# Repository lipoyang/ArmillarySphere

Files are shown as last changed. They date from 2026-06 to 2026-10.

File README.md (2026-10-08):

# 動く渾天儀
ステッピングモータで動く渾天儀です。

## 解説
* [動く渾天儀 | ProtoPedia](https://protopedia.net/prototype/8534) (日本語記事)
* [Motorized Armillary Sphere - Hackster.io](https://www.hackster.io/lipoyang/motorized-armillary-sphere-933569) (英文記事)

## ファイル
* [./app/](./app/) : Webアプリのソース (Chrome系ブラウザ対応。iOSは非対応)
* [./firm/](./firm/) : マイコンのソース (PlatformIOのプロジェクト)
* [./hard/](./hard/) : 回路の資料
* [./mechanical/](./mechanical/) : 機械設計 (Autodesk Fusionで設計)

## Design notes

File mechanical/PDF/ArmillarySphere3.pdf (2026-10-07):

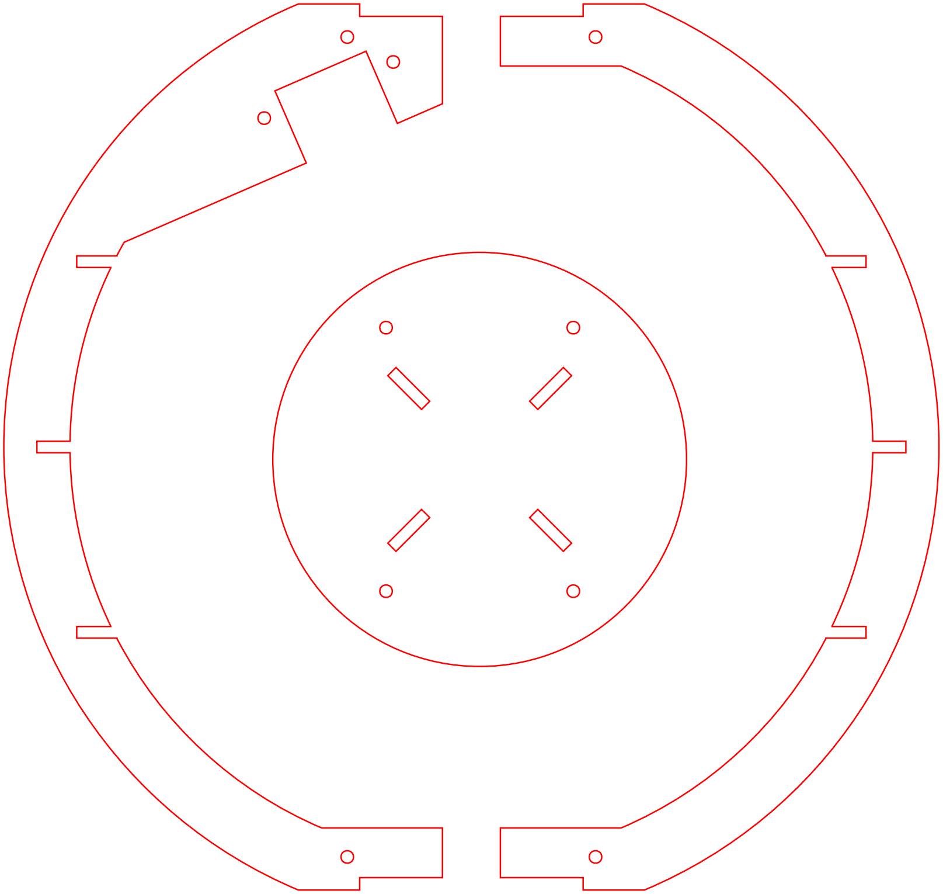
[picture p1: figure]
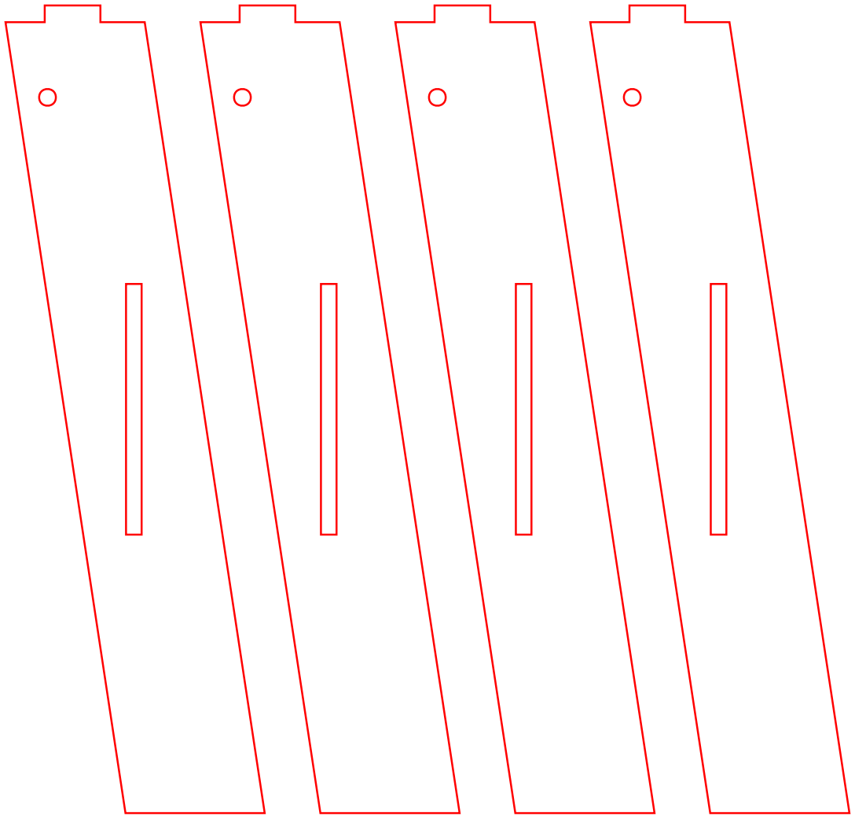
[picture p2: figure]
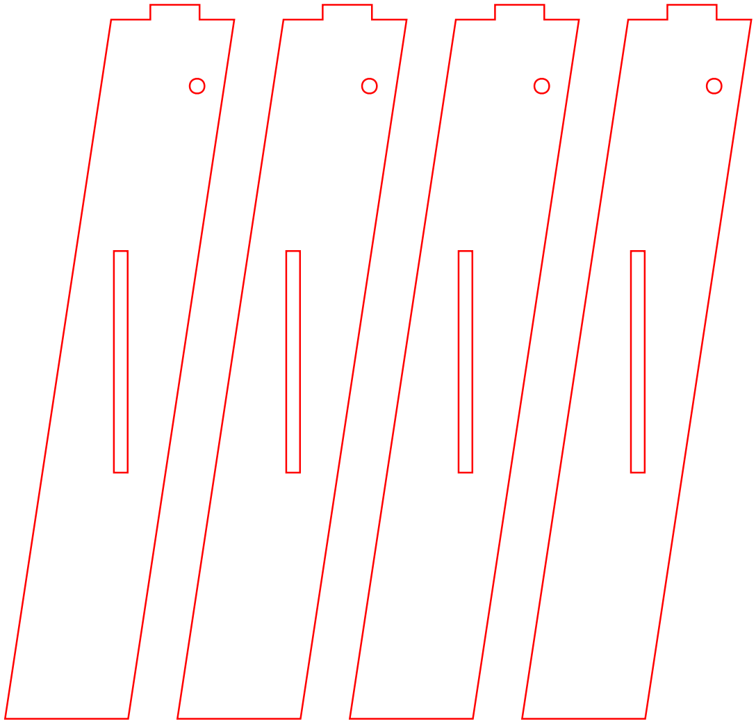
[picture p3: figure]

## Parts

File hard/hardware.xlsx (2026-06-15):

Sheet: 部品表
型番 | 説明 | 個数
~~XIAO nRF52840~~ | ~~マイコン~~ | ~~1~~
M5Stack Basic | マイコン | 1
Pololu DRV8825 モータドライバモジュール | ステッピングモータドライバモジュール | 2
24BYJ48 (12V) | 2相ユニポーラ ステッピングモータ ステップ角 = 5.625°、ギア比 = 1/64 | 2
SK8552 | ホールセンサ | 2
橙色LED (汎用品) | 太陽の表示用LED | 1
SNM022A-12 | スリップリング 12極 | 1
ACアダプタ 12V 1.5A (汎用品) | 電源用、DCプラグ φ2.1mm | 1
ユニバーサル基板 Cタイプ (汎用品) | 72×47mm ノンスルーホール | 1
JST EH 4ピン | モータとホールセンサのケーブル用コネクタ | 3
JST EH 2ピン | LEDのケーブル用コネクタ | 1
DCジャック φ2.1mm (汎用品) | 電源用 | 1
BP5293-50 | DCDCコンバータ 5V 1A | 1
電解コンデンサ 33uF 10V (汎用品) | 電源安定用 | 1
ショットキーバリアダイオード SS2040FL | 5V電源の衝突防止用ダイオード | 1
NPNデジトラ DTC014EEB | LEDのオンオフ用デジトラ | 1
100Ω抵抗 (汎用品) | LEDの電流制限抵抗 | 1

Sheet: マイコンのピンピン配置
ピン | 接続先 | ピン | 接続先 | 参考 | https://wiki.seeedstudio.com/ja/XIAO_BLE/
D0 | モータ1 DIR | VBUS | 5V
D1 | モータ1 STEP | GND | GND
D2 | モータ2 DIR | 3.3V | 3.3V
D3 | モータ2 STEP | D10 | ホールセンサ2
D4 | 未接続 | D9 | ホールセンサ1
D5 | 未接続 | D8 | LED
D6 | 未接続 | D7 | 未接続

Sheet: モータドライバのピン配置
ピン | 機能 | 接続先 | ピン | 機能 | 接続先 | 参考 | https://www.pololu.com/product/2133
8 | nENABLE | GND | 1 | VMOT | +12V
7 | MODE0 | 未接続 | 2 | GND | GND
6 | MODE1 | 未接続 | 3 | B2 | モータ
5 | MODE2 | 未接続 | 4 | B1 | モータ
4 | nRESET | +3.3V | 5 | A1 | モータ
3 | nSLEEP | +3.3V | 6 | A2 | モータ
2 | STEP | マイコン | 7 | FAULT | 未接続
1 | DIR | マイコン | 8 | GND | GND

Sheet: コネクタのピン配置
■ モータ
ピン | 信号名
1 | B2
2 | B1
3 | A1
4 | A2
■ LED
ピン | 信号名
1 | アノード
2 | カソード
■ ホールセンサ
ピン | 信号名
1 | +3.3V
2 | ホールセンサ1
3 | ホールセンサ2
4 | GND

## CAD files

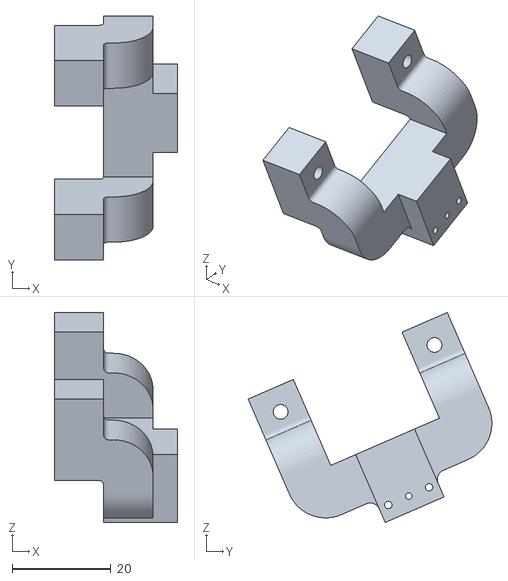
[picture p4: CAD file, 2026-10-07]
mechanical/STL/motor2_adapter.stl
25.0 x 49.4 x 42.5

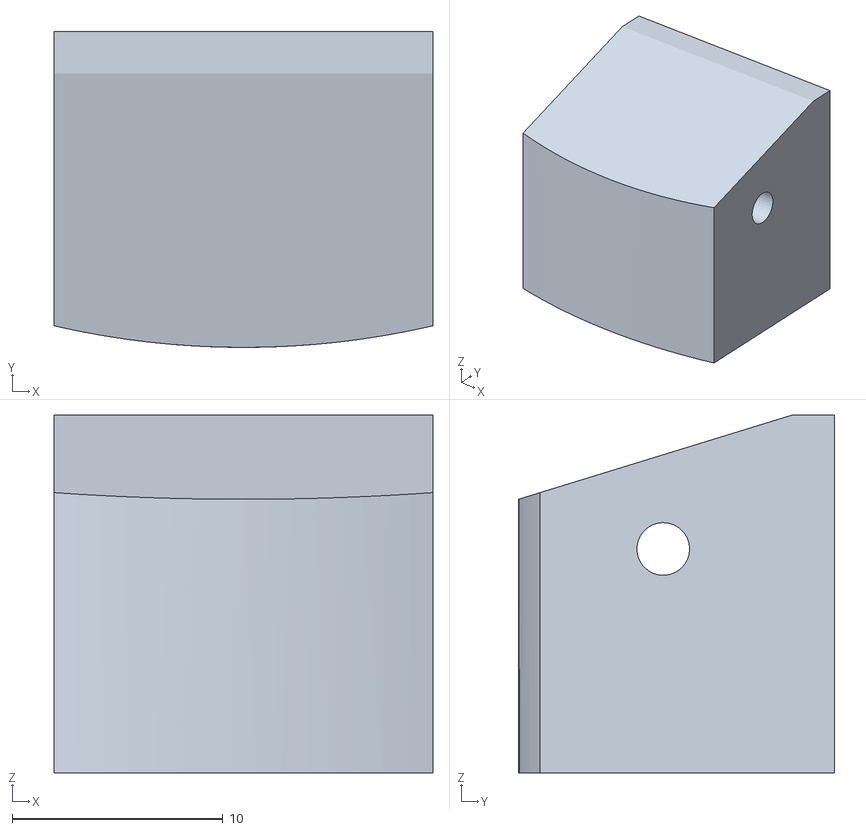
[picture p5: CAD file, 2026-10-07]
mechanical/STL/meridian_spacer.stl
18.0 x 15.0 x 17.0

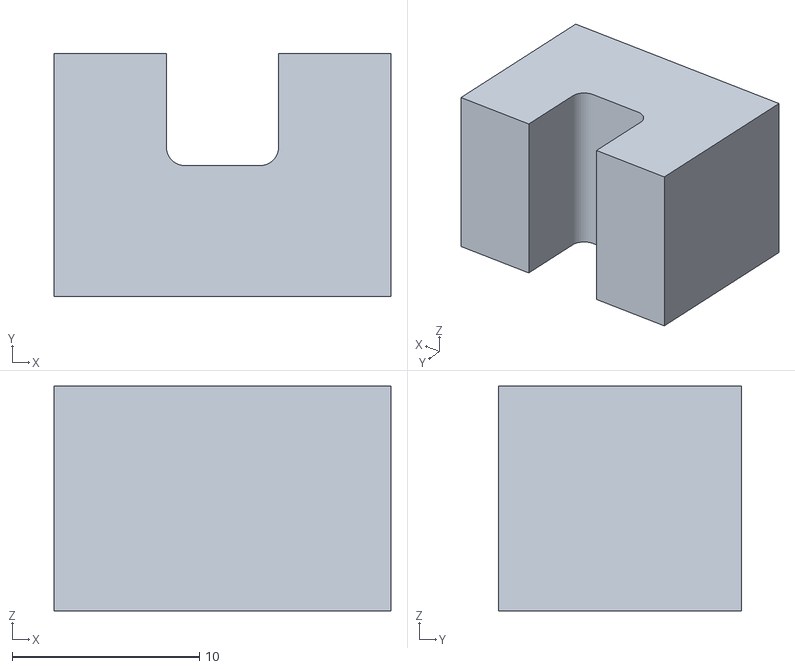
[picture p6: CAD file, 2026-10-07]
mechanical/STL/hall_adapter.stl
18.0 x 13.0 x 12.0

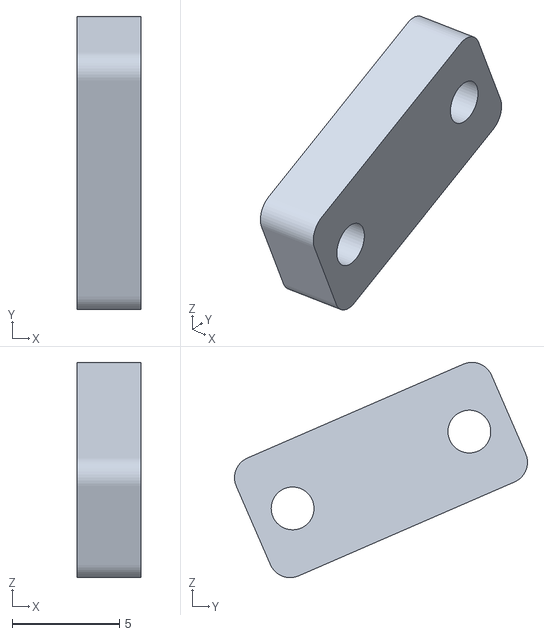
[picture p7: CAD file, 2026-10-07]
mechanical/STL/moto2_adapter_sub.stl
3.00 x 13.7 x 10.1

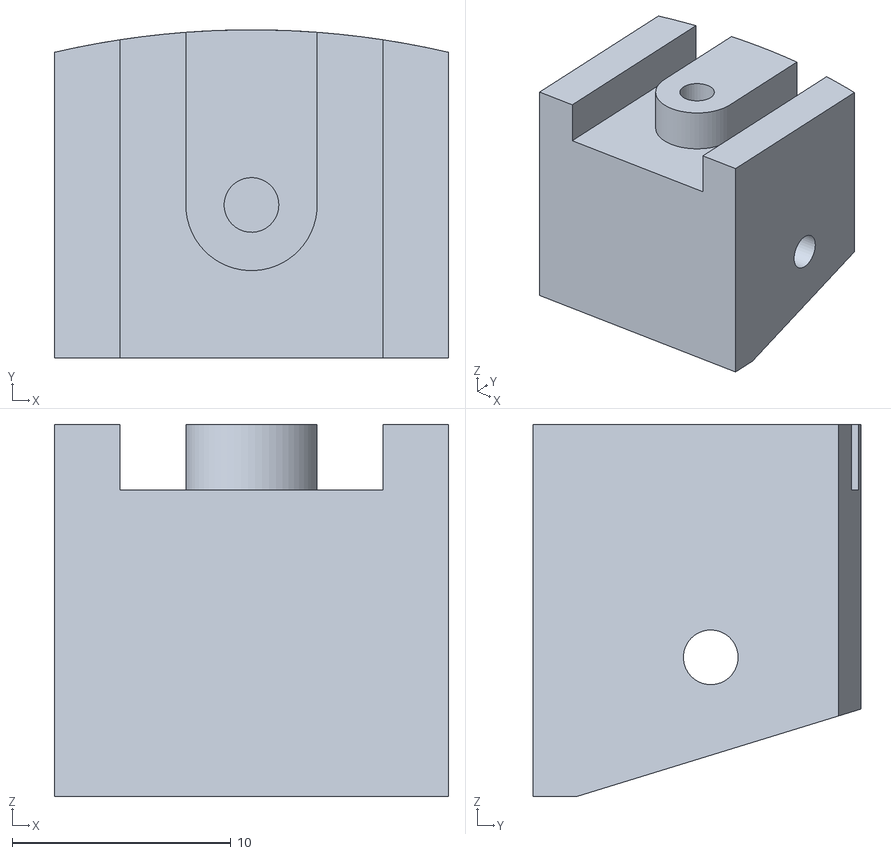
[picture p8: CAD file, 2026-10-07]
mechanical/STL/meridian_spacer_2.stl
18.0 x 15.0 x 17.0

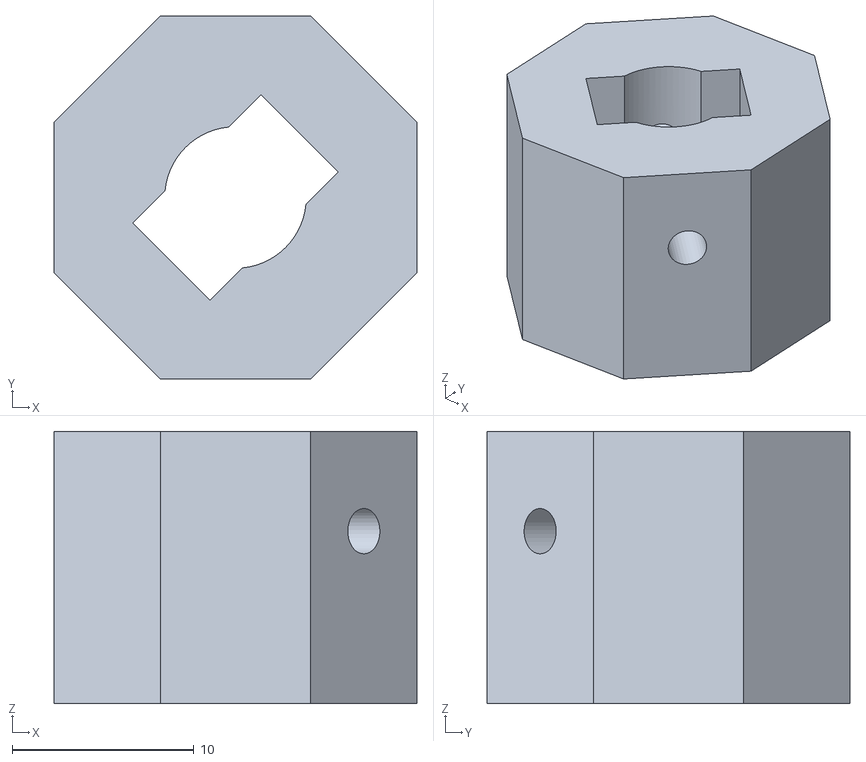
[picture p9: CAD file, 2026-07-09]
mechanical/STL/slipring_adapter.stl
20.0 x 20.0 x 15.0

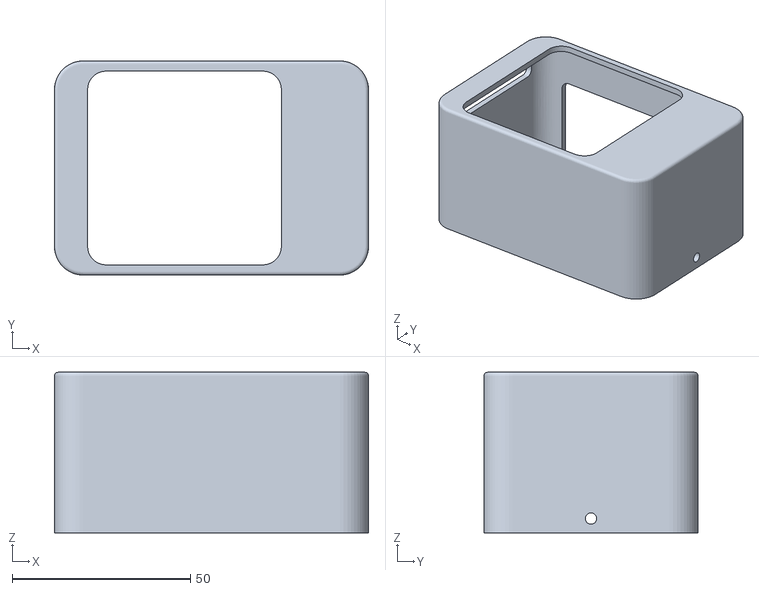
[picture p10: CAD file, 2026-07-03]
mechanical/STL/ControllerCace_top.stl
88.0 x 60.0 x 45.0

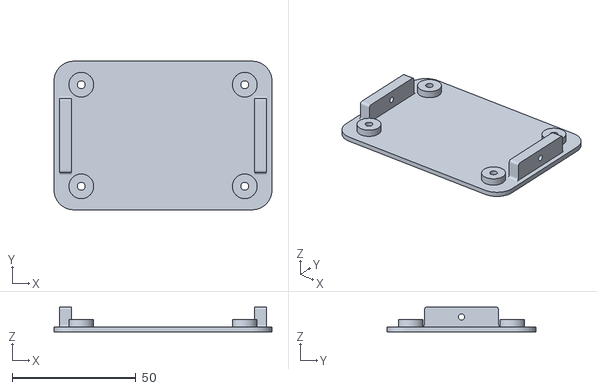
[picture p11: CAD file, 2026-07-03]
mechanical/STL/ControllerCace_bottom.stl
88.0 x 60.0 x 10.0

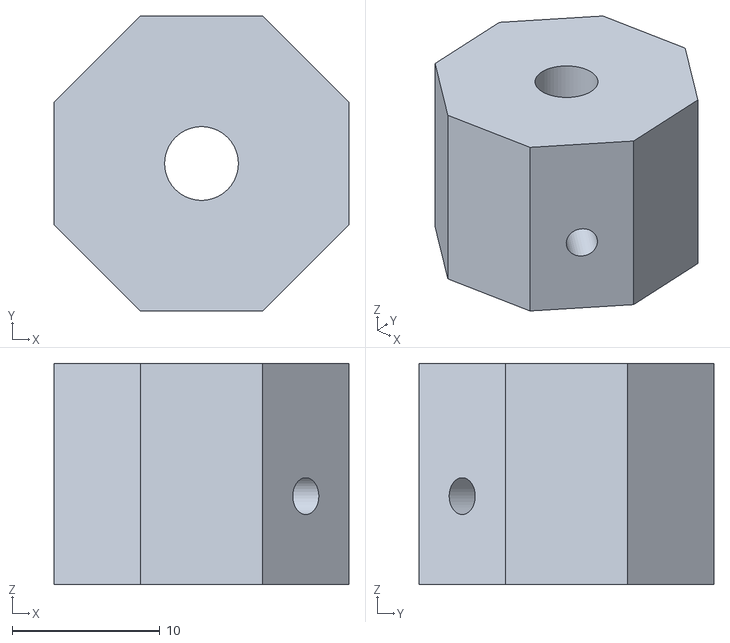
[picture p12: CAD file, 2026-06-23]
mechanical/STL/motor_adapter.stl
20.0 x 20.0 x 15.0

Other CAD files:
mechanical/model/ArmillarySphere.f3d
mechanical/model/ControllerCase.f3d

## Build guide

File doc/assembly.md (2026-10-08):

# 組立て
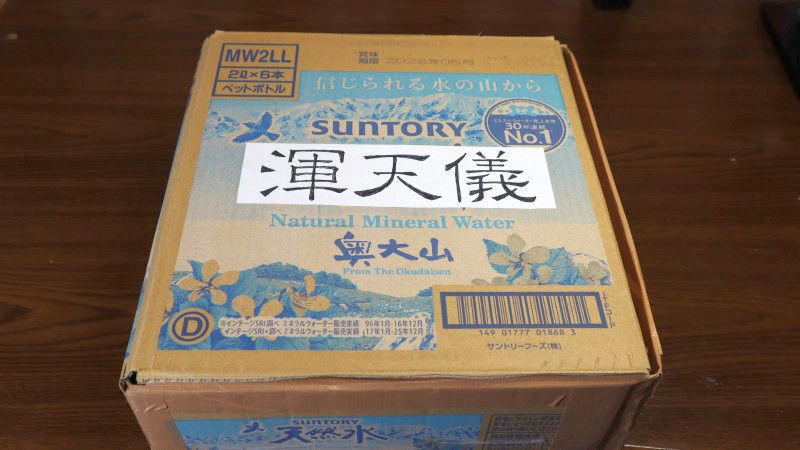
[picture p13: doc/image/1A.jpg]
図1A
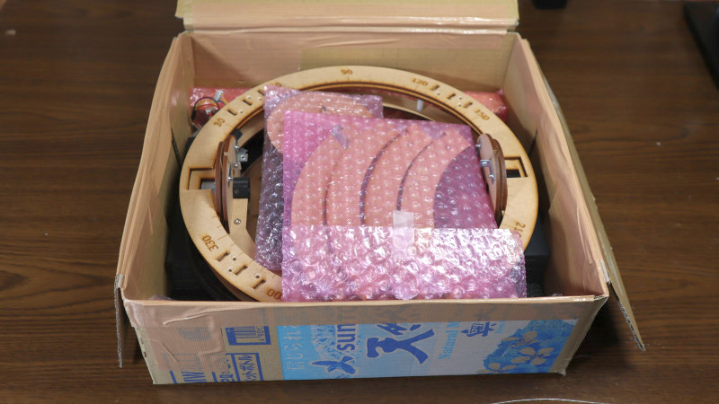
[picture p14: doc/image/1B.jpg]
図1B
　

## (1) 台
### (1.1) 底板に支持環を取り付ける (M3-6mmナベネジ)
NE(艮)、SE(巽)、SW(坤)、NW(乾)の順に仮止め。

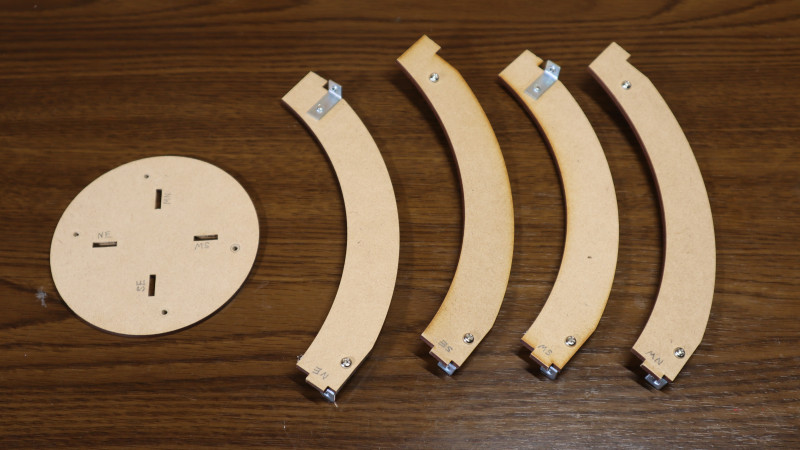
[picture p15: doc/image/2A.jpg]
図2A
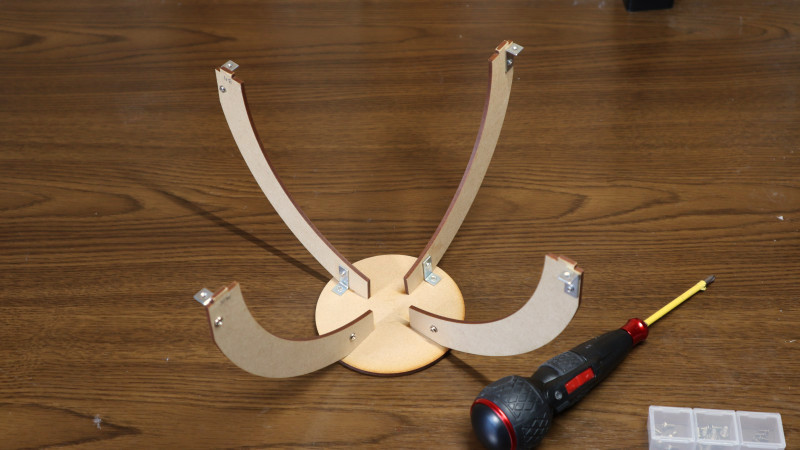
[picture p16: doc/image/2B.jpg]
図2B
　

### (1.2) 地平環に支持環を取り付ける (M3-6mm低頭ネジ)
NE(艮)、SE(巽)、SW(坤)、NW(乾)の順に仮止め。その後、(1.1) (1.2) の本締め。

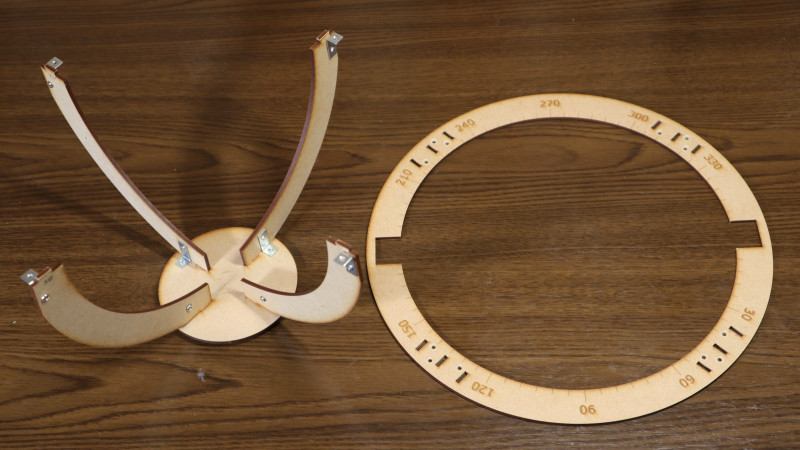
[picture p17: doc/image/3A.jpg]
図3A
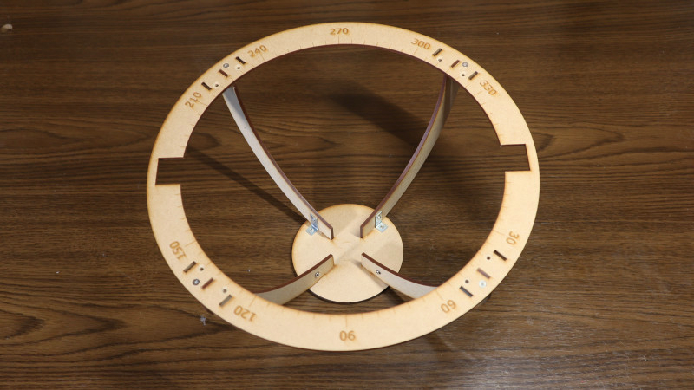
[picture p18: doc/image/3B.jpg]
図3B
　

### (1.3) 地平環に脚を取り付ける (M3-6mm低頭ネジ)
NE(艮)、SE(巽)、SW(坤)、NW(乾)の順に。

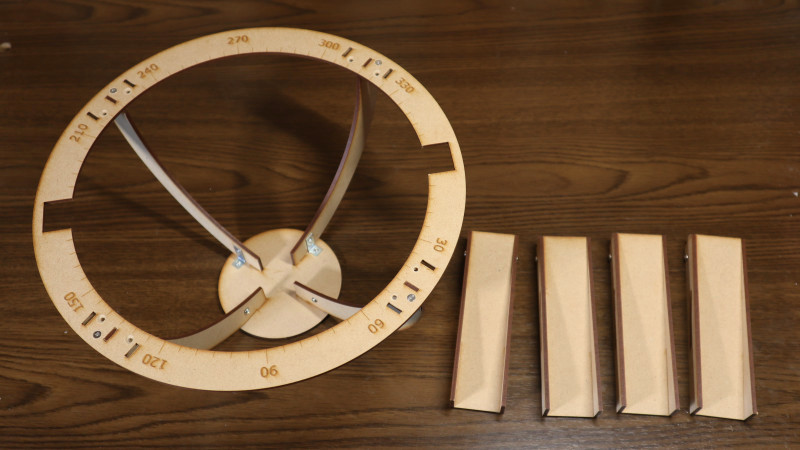
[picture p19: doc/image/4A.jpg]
図4A
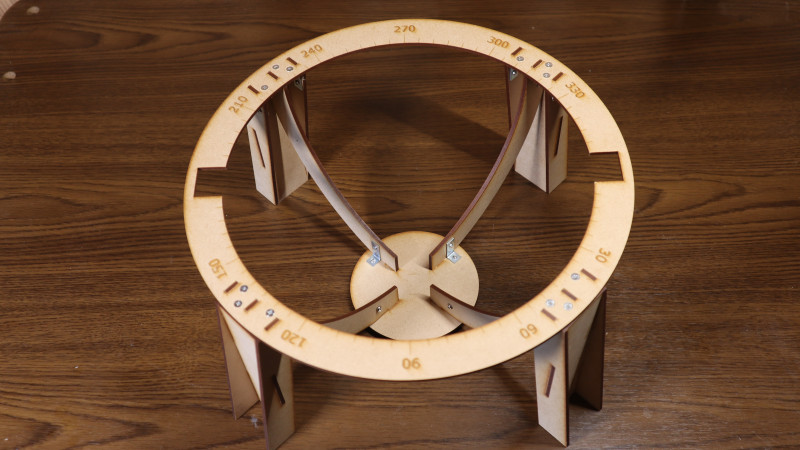
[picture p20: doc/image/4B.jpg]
図4B
　

## (2) 天球
### (2.1) 北回帰環・赤道環・南回帰環を18時(冬至)の天経環に取り付ける
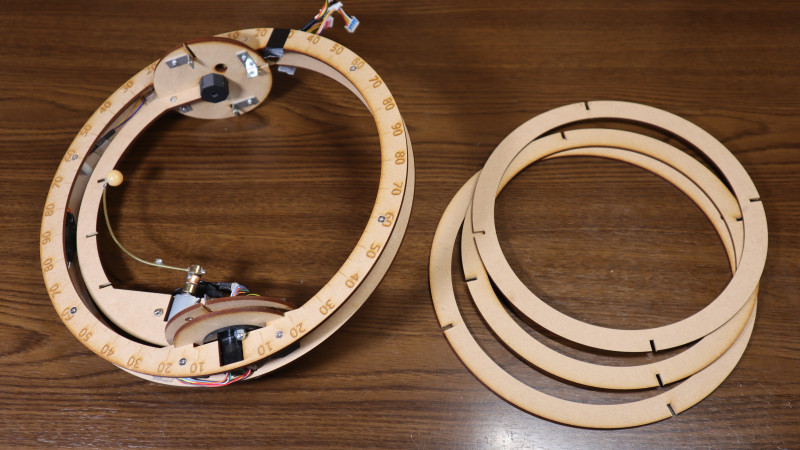
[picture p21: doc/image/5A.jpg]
図5A
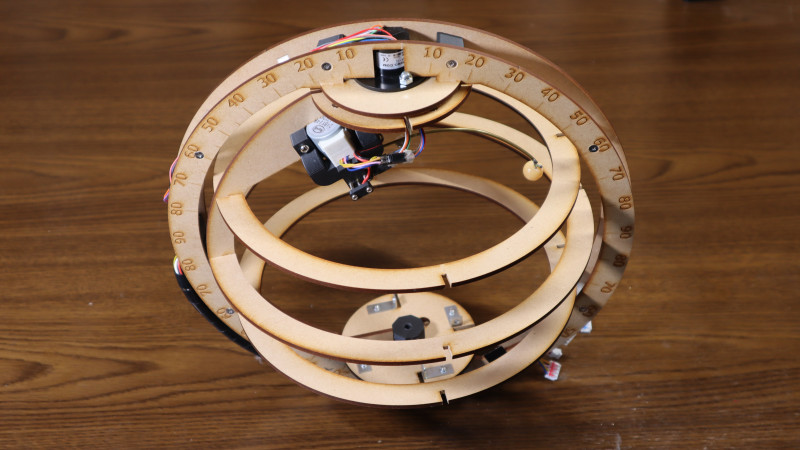
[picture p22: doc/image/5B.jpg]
図5B
　

### (2.2) 天経環を北極環と南極環に取り付ける (M3-6mmナベネジ)
0時(春分)、6時(夏至)、12時(秋分)の順に仮止め。その後、本締め。

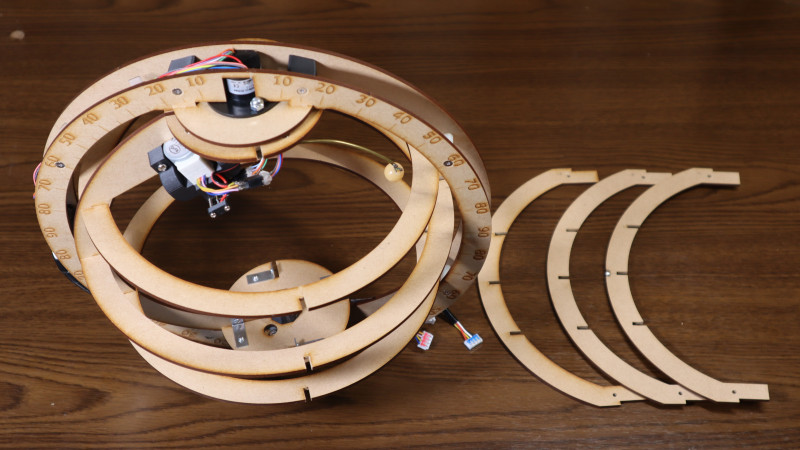
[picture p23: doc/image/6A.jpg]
図6A
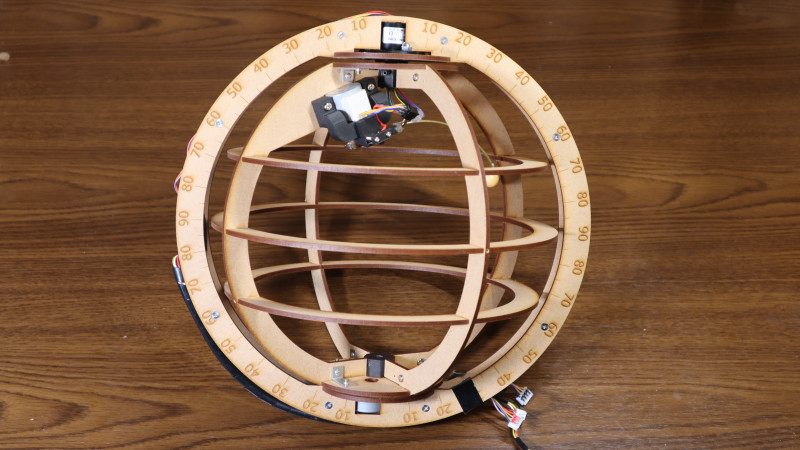
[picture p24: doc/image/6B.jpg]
図6B
　

## (3) 黄道環
### (3.1) Pisces(双魚宮)を0時(春分)の天経環に取り付ける (M2-6mm皿ネジ)
ここでは仮止めにしておく。

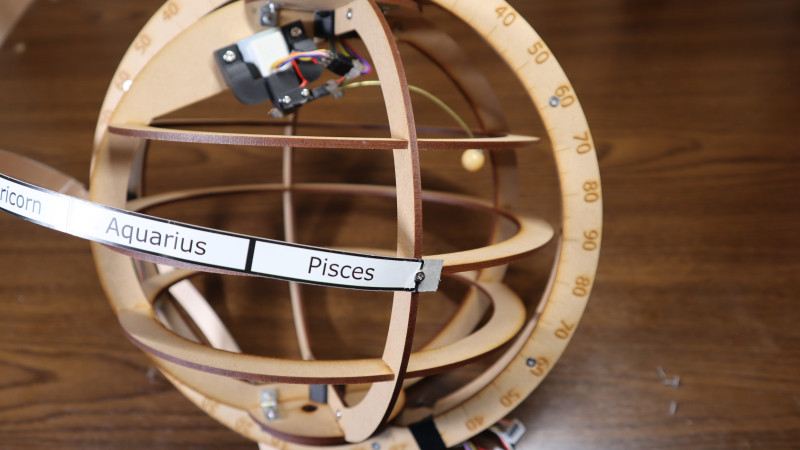
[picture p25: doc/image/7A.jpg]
図7A


### (3.2) Capricorn(磨羯宮)を18時(冬至)の天経環に取り付ける (M2-6mm皿ネジ)
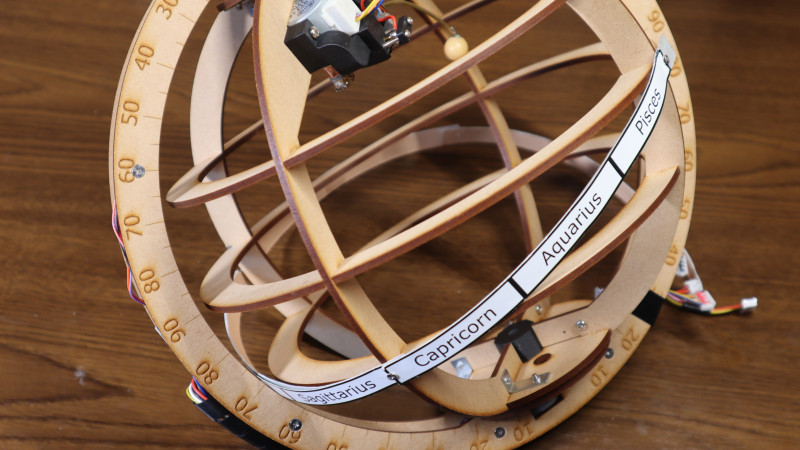
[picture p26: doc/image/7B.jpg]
図7B


### (3.3) Libra(天秤宮)を12時(秋分)の天経環に取り付ける (M2-6mm皿ネジ)
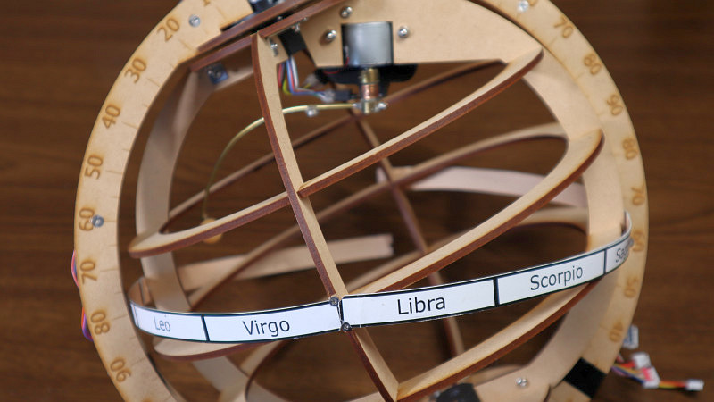
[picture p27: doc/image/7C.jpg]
図7C


### (3.4) Cancer(巨蟹宮)を6時(夏至)の天経環に取り付ける (M2-6mm皿ネジ)
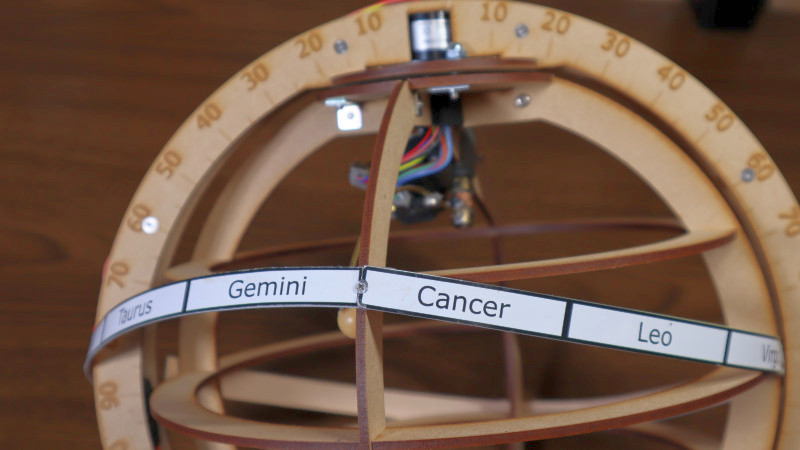
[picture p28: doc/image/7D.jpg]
図7D


### (3.5) Aries(白羊宮)を0時(春分)の天経環に取り付ける (M2-6mm皿ネジ)
ここで本締めする。

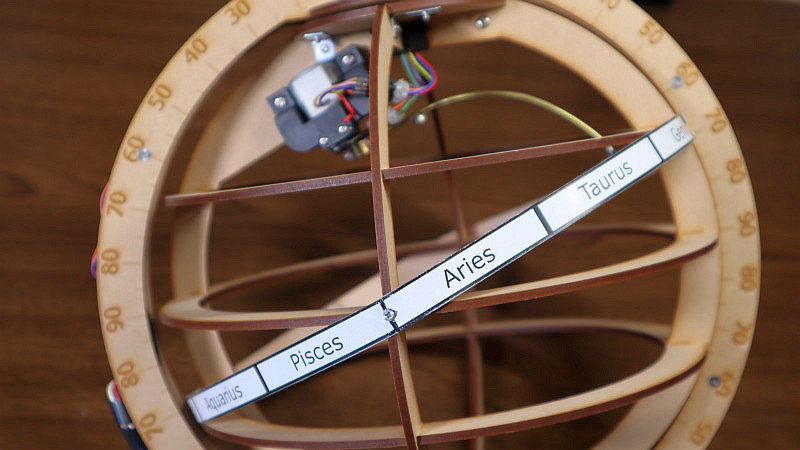
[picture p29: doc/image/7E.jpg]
図7E


### (4) 天球を台に乗せて完成
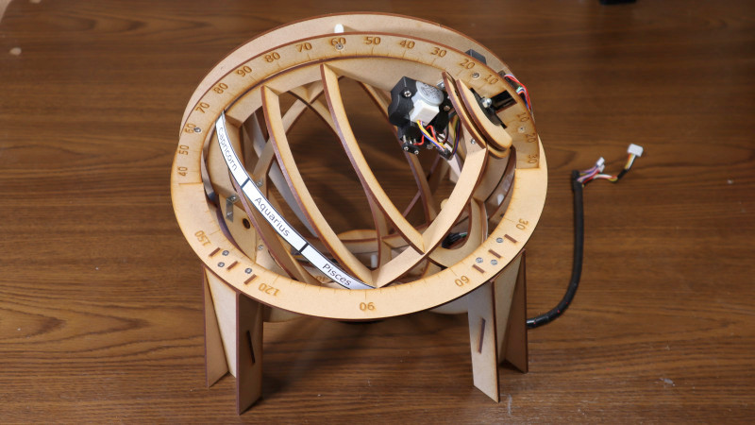
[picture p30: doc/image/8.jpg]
図8


# 解体
基本的には組立ての逆手順である。

## (1) 黄道環
**(1.1) Aries(白羊宮)を0時(春分)の天経環から取り外す (M2-6mm皿ネジ)**  
**(1.2) Cancer(巨蟹宮)を6時(夏至)の天経環から取り外す (M2-6mm皿ネジ)**  
**(1.3) Libra(天秤宮)を12時(秋分)の天経環から取り外す (M2-6mm皿ネジ)**  
**(1.4) Capricorn(磨羯宮)を18時(冬至)の天経環から取り外す (M2-6mm皿ネジ)**  
**(1.5) Pisces(双魚宮)を0時(春分)の天経環から取り外す (M2-6mm皿ネジ)**  

## (2) 天球
**(2.1) 天経環を、北極環と南極環から取り外す (M3-6mmナベネジ)**  
0時(春分)、6時(夏至)、12時(秋分)の順に。

**(2.2) 北回帰環、赤道環、南回帰環を、18時(冬至)の天経環から取り外す**

## (3) 台
**(3.1) 地平環から脚を取り外す (M3-6mm低頭ネジ)**  
NE(艮)、SE(巽)、SW(坤)、NW(乾)の順に。

**(3.2) 地平環から支持環を取り外す (M3-6mm低頭ネジ)**   
NE(艮)、SE(巽)、SW(坤)、NW(乾)の順に。

**(3.3) 底板から支持環を取り外す (M3-6mmナベネジ)**  
NE(艮)、SE(巽)、SW(坤)、NW(乾)の順に。

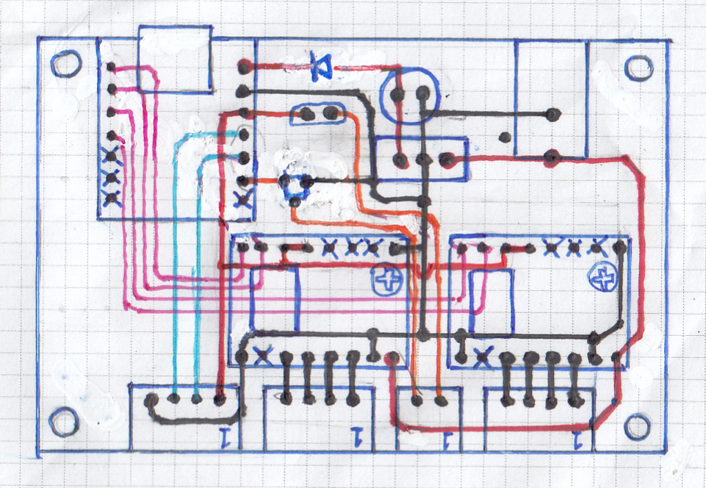
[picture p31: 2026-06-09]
hard/wiring_diagram.jpg

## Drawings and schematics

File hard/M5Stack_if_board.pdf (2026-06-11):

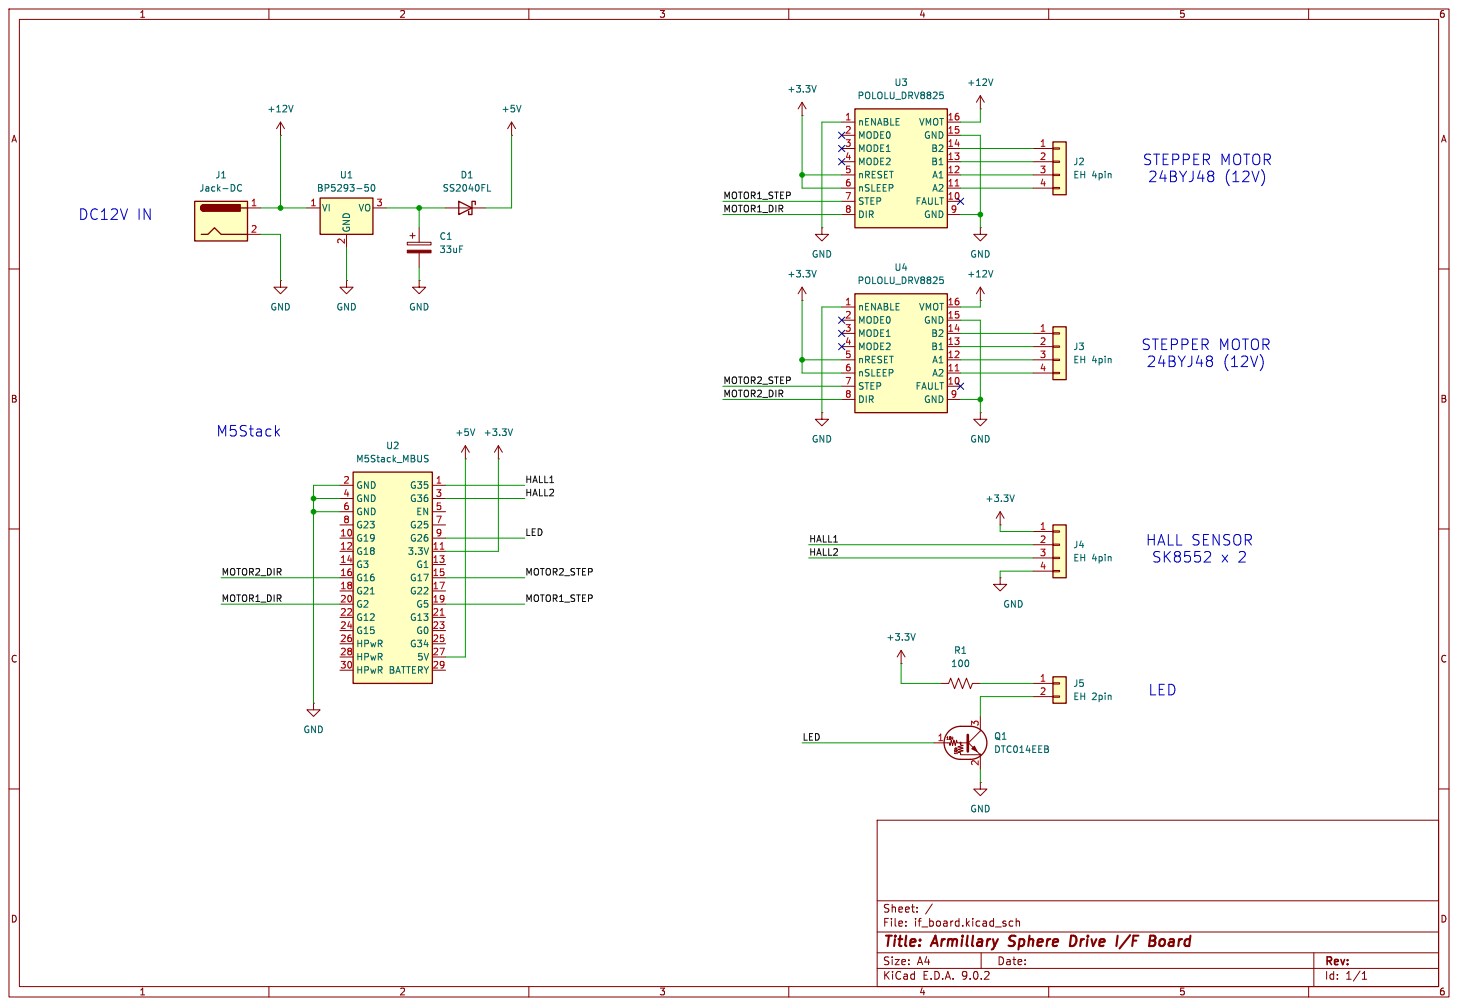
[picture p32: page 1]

File: if_board.kicad_sch Sheet: /
Id: 1/1 Title: Armillary Sphere Drive I/F Board

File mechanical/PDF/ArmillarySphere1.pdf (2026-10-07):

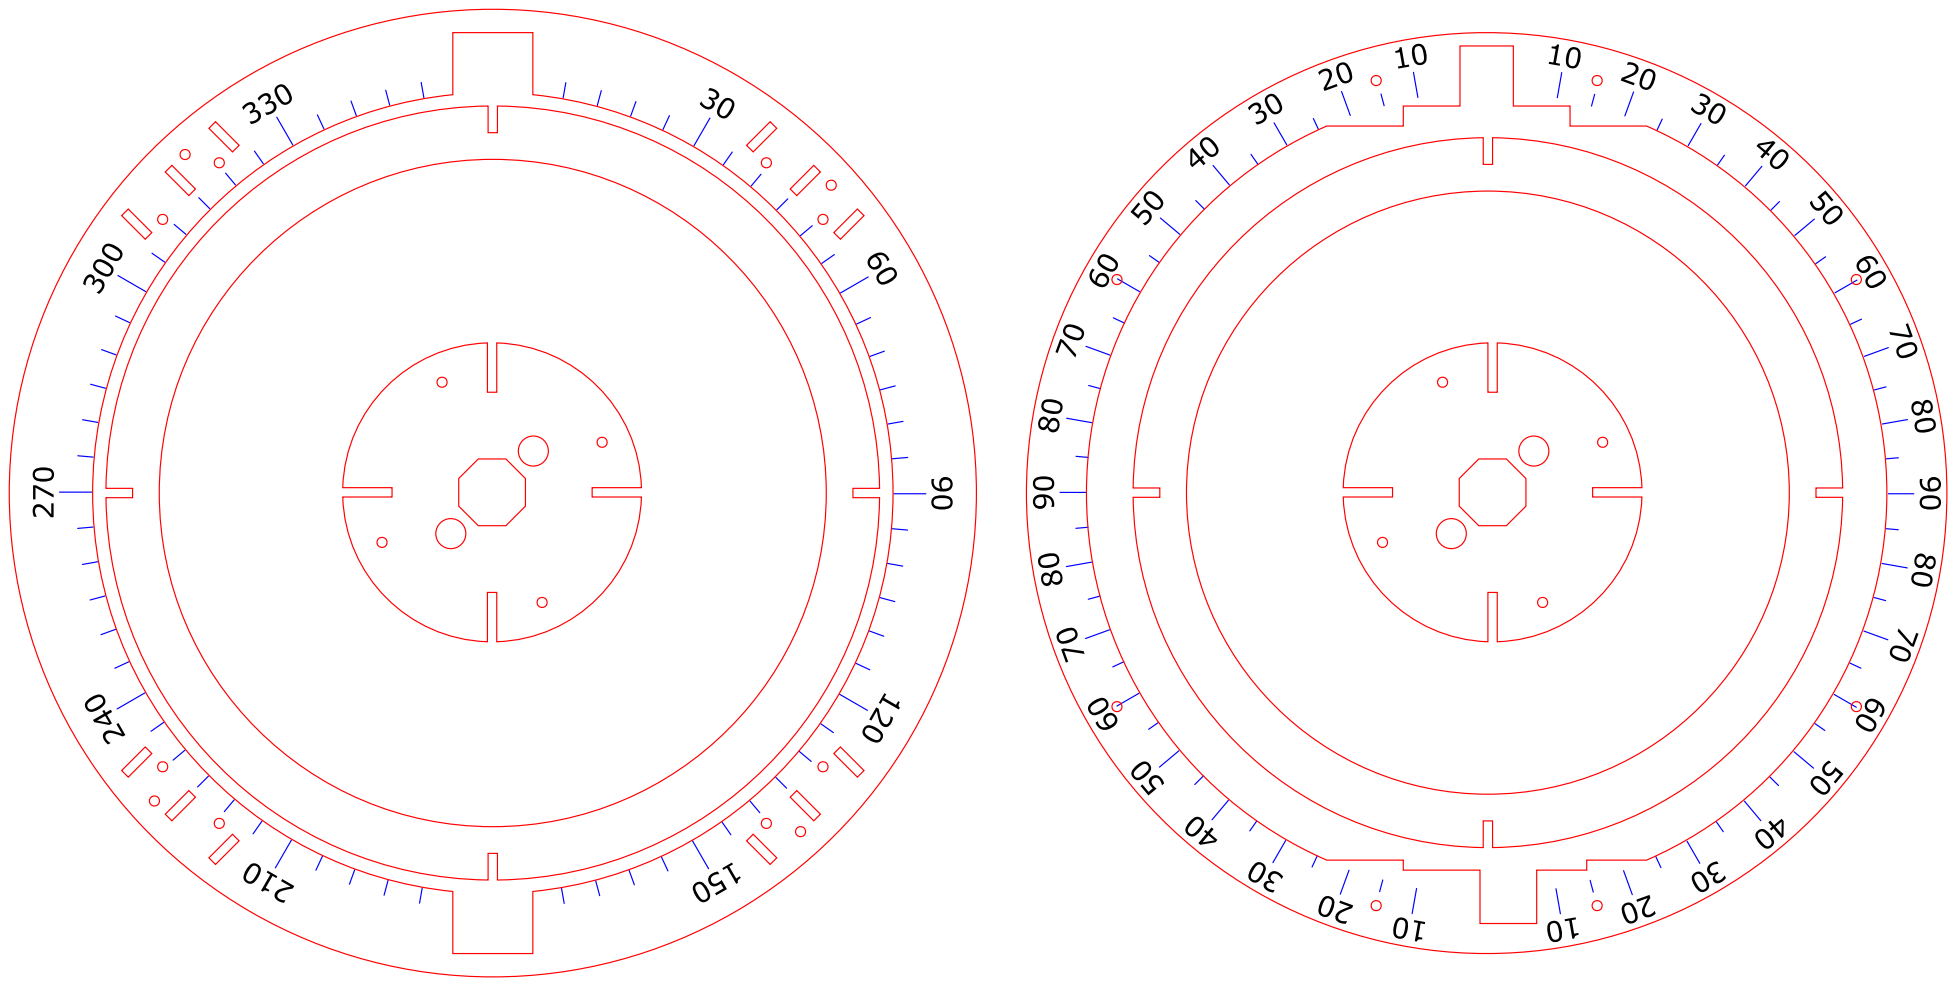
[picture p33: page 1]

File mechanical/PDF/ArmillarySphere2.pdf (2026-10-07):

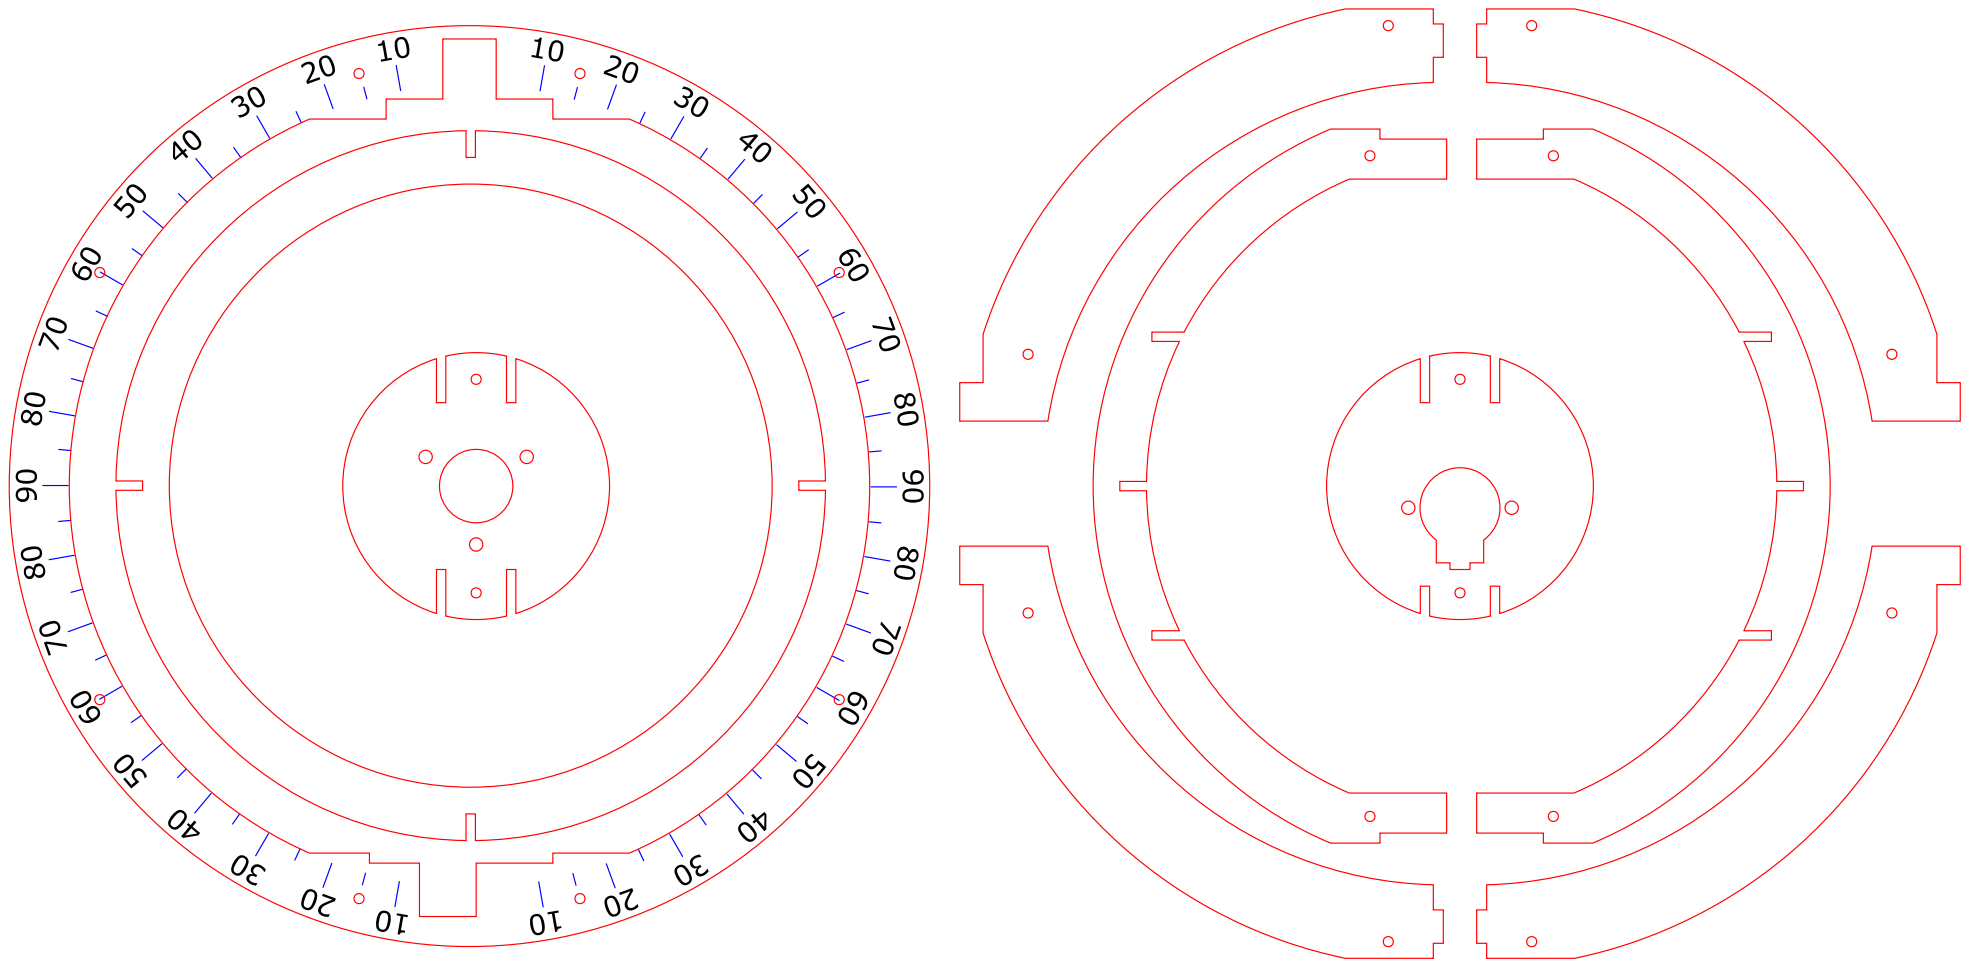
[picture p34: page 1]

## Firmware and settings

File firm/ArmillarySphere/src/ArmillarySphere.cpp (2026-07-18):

#include <math.h>
#include "DRV8825.h"
#include "SunCalc.h"
#include "BleCommand.h"
#include "M5UI.h"
#include "Debug.h"

// ピン番号
#if 1
// M5Stack ピン割り当て
#define MOTOR1_DIR   2
#define MOTOR1_STP   5
#define MOTOR2_DIR   16
#define MOTOR2_STP   17
#define LED_SUN      26
#define HALL_SENSOR1 35
#define HALL_SENSOR2 36
#else
// XIAO nRF52840 ピン割り当て
#define MOTOR1_DIR   D0
#define MOTOR1_STP   D1
#define MOTOR2_DIR   D2
#define MOTOR2_STP   D3
#define LED_SUN      D8
#define HALL_SENSOR1 D9
#define HALL_SENSOR2 D10
#endif

// 1ステップ=5.625°= 360°/64, ギア比1/32, フルステップ
#define STEP_PER_REV (64*32*1)

// ステッピングモータ
DRV8825 motor1(MOTOR1_DIR, MOTOR1_STP, 1, STEP_PER_REV);
DRV8825 motor2(MOTOR2_DIR, MOTOR2_STP, 1, STEP_PER_REV);

// 初期化フラグ
static bool initializing = false;
// モータの角度[deg]
static double theta1 = 0.0;
static double theta2 = 0.0;

// モータの回転速度上限[deg/sec]
const double V_MAX = 60.0;

// 経度
static float longitude = 135.0f; // 東経135度

// 太陽の位置計算クラス
SunCalc sun;

// BLEコマンドクラス
BleCommand bleCommand;

// M5Stack UIクラス
M5UI ui;

// 日時
struct DateTime {
    int y; // 年
    int m; // 月
    int d; // 日
    int h; // 時
    int n; // 分
};

// うるう年判定
bool isLeap(int y) {
    return (y % 4 == 0 && y % 100 != 0) || (y % 400 == 0);
}

// 月ごとの日数
int daysInMonth(int y, int m){
    static const int days[12] = { 31,28,31,30,31,30,31,31,30,31,30,31 };
    if (m == 2 && isLeap(y)) return 29;
    return days[m-1];
}

// ローカル時刻の計算
// utc : UTC時刻
// timezone : タイムゾーン [時]
// return : ローカル時刻
DateTime utc2local(DateTime &utc, int timezone)
{
    DateTime t = utc;

    // 1) 時差を加算
    t.h += timezone;

    // 2) 日の繰り上がり・繰り下がり
    if(t.h >= 24){
        t.h -= 24;
        t.d += 1;
    }else if(t.h < 0){
        t.h += 24;
        t.d -= 1;
    }

    // 3) 月・年の繰り上がり・繰り下がり
    int dim = daysInMonth(t.y, t.m);
    if(t.d > dim){
        t.m += 1;
        if(t.m > 12){
            t.m = 1;
            t.y += 1;
        }
        t.d = 1;
    }else if(t.d < 1){
        t.m -= 1;
        if(t.m < 1){
            t.m = 12;
            t.y -= 1;
        }
        t.d += daysInMonth(t.y, t.m);
    }
    return t;
}

// -360～+360°の角度を-180°～+180°に変換する
static double deg_range180(double x)
{
    if(x >  180.0) x -= 360.0;
    if(x < -180.0) x += 360.0;
    return x;
}

// 初期位置出し(太陽が春分点で南中)
static void initPosition()
{
    bleCommand.setBusy(true);
    
    Serial.println("Motor position initializing...");

    ui.setLongitude(longitude);
    ui.setDate(2026, 3, 20);
    ui.setTime(12, 0);
    ui.setMode(MODE_INIT);

    int state[2]    = {0, 0};
    int position[2];
    int hall[2];
    DRV8825 *motor[2] = {&motor1, &motor2};
    
    // ホールセンサ入力の取得
    hall[0] = digitalRead(HALL_SENSOR1);
    hall[1] = digitalRead(HALL_SENSOR2);
    
    // もしホールセンサがHIGHなら少し逆転しておく
    if(hall[0] == HIGH) motor1.rotateT(-30, 0.5);
    if(hall[1] == HIGH) motor2.rotateT(-30, 0.5);
    while(!motor1.isIdle() || !motor2.isIdle()){
        motor1.update();
        motor2.update();
        delay(1);
    }
    // 正転開始
    motor1.rotateT(360, 6);
    motor2.rotateT(360, 6);
    
    while(true)
    {
        // ホールセンサ入力の取得
        hall[0] = digitalRead(HALL_SENSOR1);
        hall[1] = digitalRead(HALL_SENSOR2);
        
        // モータごとの制御
        for(int i=0; i<2; i++)
        {
            switch(state[i])
            {
            // 正転中(ホールセンサがHIGHになるまで進む)
            case 0:
                if (hall[i] == HIGH){
                    state[i] = 1;
                    position[i] = motor[i]->getPos();
                    motor[i]->rotateT(180, 12);
                }
                break;
            // 正転中(ホールセンサがLOWになるまでさらに進む)
            case 1:
                if (hall[i] == LOW){
                    state[i] = 2;
                    //　少し戻る (メカのセッティングによって要調整)
                  //int step = (motor[i]->getPos() - position[i]) / 2; // (追加で進んだステップ数の半分だけ戻る)
                    int step = (motor[i]->getPos() - position[i]);
                    motor[i]->setStepV(-step, 100);
                }
                break;
            // 逆転中(少し戻る)
            case 2:
                if(motor[i]->isIdle()){
                    state[i] = 3;
                }
                break;
            // 初期位置出し完了
            case 3:
                break;
            }
        }
        
        // 両方のモータの初期位置出しが完了したら終了
        if((state[0] == 3) && (state[1] == 3)){
            Serial.println("Motor position initialized!");
            break;
        }
        
        // モータの制御更新
        motor1.update();
        motor2.update();
        delay(1);
        
        // BLEタスクの実行 TODO
        bleCommand.task();
    }
    bleCommand.setBusy(false);

    ui.setMode(MODE_NORMAL);
}

// 初期位置コマンドのとき
static bool onCommandInit()
{
    Serial.println("onCommandInit");
    
    // モータのアイドル判定
    bool motors_idle = motor1.isIdle() && motor2.isIdle();
    if(!motors_idle){
        Serial.println("Motor Busy");
        return false;
    }
    
    initializing = true;
    return true;
}

// 停止コマンドのとき
static bool onCommandStop()
{
    Serial.println("onCommandStop");
    ui.setMode(MODE_NORMAL);
    
    motor1.stop();
    motor2.stop();
    return true;
}

// 自転コマンドのとき
static bool onCommandRotation()
{
    Serial.println("onCommandRotation");
    
    // モータのアイドル判定
    bool motors_idle = motor1.isIdle() && motor2.isIdle();
    if(!motors_idle){
        Serial.println("Motor Busy");
        return false;
    }
    ui.setMode(MODE_ROTATION);
    
    motor1.rotateV(V_MAX);
    return true;
}

// 公転コマンドのとき
static bool onCommandRevolution()
{
    Serial.println("onCommandRevolution");
    
    // モータのアイドル判定
    bool motors_idle = motor1.isIdle() && motor2.isIdle();
    if(!motors_idle){
        Serial.println("Motor Busy");
        return false;
    }
    ui.setMode(MODE_REVOLUTION);
    
    motor2.rotateV(V_MAX);
    return true;
}

// デモ1コマンドのとき
static bool onCommandDemo1()
{
    Serial.println("onCommandDemo1");
    
    // モータのアイドル判定
    bool motors_idle = motor1.isIdle() && motor2.isIdle();
    if(!motors_idle){
        Serial.println("Motor Busy");
        return false;
    }
    ui.setMode(MODE_DEMO1);
    
    motor1.rotateV(V_MAX);
    motor2.rotateV(V_MAX);
    return true;
}

// デモ2コマンドのとき
static bool onCommandDemo2()
{
    Serial.println("onCommandDemo2");
    
    // モータのアイドル判定
    bool motors_idle = motor1.isIdle() && motor2.isIdle();
    if(!motors_idle){
        Serial.println("Motor Busy");
        return false;
    }
    ui.setMode(MODE_DEMO2);
    
    motor1.rotateV(V_MAX);
    motor2.rotateV(V_MAX / 4);
    return true;
}

// 経度・UTC日時の設定のとき
static bool onCommandLonTime()
{
    Serial.println("onCommandLonTime");

    // モータのアイドル判定
    bool motors_idle = motor1.isIdle() && motor2.isIdle();
    if(!motors_idle){
        Serial.println("Motor Busy");
        return false;
    }

    float lon = bleCommand.lonTime.lon;
    int y = bleCommand.lonTime.year;
    int m = bleCommand.lonTime.month;
    int d = bleCommand.lonTime.day;
    int h = bleCommand.lonTime.hour;
    int n = bleCommand.lonTime.min;
    int tz = bleCommand.lonTime.timezone;

    DateTime utc = {y, m, d, h, n};
    DateTime localTime = utc2local(utc, tz); 

    DEBUG_PRINT("UTC %d/%02d/%02d %02d:%02d %d\n", y, m, d, h, n, tz);
    DEBUG_PRINT("Local %d/%02d/%02d %02d:%02d\n", localTime.y, localTime.m, localTime.d, localTime.h, localTime.n);

    ui.setLongitude(lon);
    ui.setDate(localTime.y, localTime.m, localTime.d);
    ui.setTime(localTime.h, localTime.n);

    longitude = lon;

    // 日時と観測地点の緯度・経度を設定して太陽の位置を計算
    sun.setDate(y, m, d, h, n, 0);
    sun.setLocation(35, lon); // 第1引数の緯度は実際には未使用
    sun.calc();
    
    // 太陽黄経λ[deg]と地方恒星時LST[deg]
    DEBUG_PRINT("Lambda = %7.3f\n", RAD2DEG(sun.lambda));
    DEBUG_PRINT("LST    = %7.3f\n", RAD2DEG(sun.t_LST));
    
    // モータの角度に換算
    double _theta2 = RAD2DEG(sun.lambda);
    DEBUG_PRINT("theta2 = %7.2f\n", _theta2);
    double _theta1 = RAD2DEG(sun.t_LST);
    DEBUG_PRINT("theta1 = %7.2f\n", _theta1);
    
    // モータの回転量
    double d_theta1 = deg_range180( _theta1 - theta1 );
    double d_theta2 = deg_range180( _theta2 - theta2 );
    theta1 = _theta1;
    theta2 = _theta2;
    DEBUG_PRINT("d_theta1 = %7.2f\n", d_theta1);
    DEBUG_PRINT("d_theta2 = %7.2f\n", d_theta2);
    
    // 回転時間
    double T1 = fabs(d_theta1 / V_MAX);
    double T2 = fabs(d_theta2 / V_MAX);
    double T = (T1 > T2) ? T1 : T2;
    DEBUG_PRINT("T = %f\n", T);
    
    // モータの回転指令
    motor1.rotateT(d_theta1, T);
    motor2.rotateT(d_theta2, T);

    return true;
}

// 接続時
static void onConnected()
{
    ui.setConnected(true);
}

// 切断時
static void onDisconnected()
{
    ui.setConnected(false);
}

// UIの操作でモード設定されたとき
static void onSetMode(OpMode mode)
{
    switch(mode){
    case MODE_NORMAL:
        onCommandStop();
        break;
    case MODE_INIT:
        onCommandInit();
        break;
    case MODE_ROTATION:
        onCommandRotation();
        break;
    case MODE_REVOLUTION:
        onCommandRevolution();
        break;
    case MODE_DEMO1:
        onCommandDemo1();
        break;
    case MODE_DEMO2:
        onCommandDemo2();
        break;
    default:
        break;
    }
}

// 初期化
void setup()
{
    Serial.begin(115200);

    ui.begin();
    ui.onSetMode = onSetMode;

    //while(!Serial);
    //delay(100);
    Serial.println("Start!");

    // モータの初期化
    motor1.begin();
    motor2.begin();
    
    // ホールセンサの初期化
    pinMode(HALL_SENSOR1, INPUT);
    pinMode(HALL_SENSOR2, INPUT);
    
    // LEDの点灯
    pinMode(LED_SUN,    OUTPUT);
    digitalWrite(LED_SUN,    HIGH);
    
    // BLEコマンドの初期化
    bleCommand.onCommandInit       = onCommandInit;
    bleCommand.onCommandStop       = onCommandStop;
    bleCommand.onCommandRotation   = onCommandRotation;
    bleCommand.onCommandRevolution = onCommandRevolution;
    bleCommand.onCommandDemo1      = onCommandDemo1;
    bleCommand.onCommandDemo2      = onCommandDemo2;
    bleCommand.onCommandLonTime    = onCommandLonTime;
    bleCommand.onConnected         = onConnected;
    bleCommand.onDisconnected      = onDisconnected;
    bleCommand.begin();

    // 初期位置出し(太陽が春分点で南中)
    initPosition();
}

// メインループ
void loop()
{
    // BLEタスク
    bleCommand.task();

    // UIタスク
    ui.task();

    // モータがアイドル状態かチェック
    static bool motors_idle_old = true;
    bool motors_idle = motor1.isIdle() && motor2.isIdle();
    if(motors_idle && !motors_idle_old){
        Serial.println("Motors rotated!");
    }
    motors_idle_old = motors_idle;
    bleCommand.setBusy(!motors_idle);
    
    // 初期位置出し
    if(initializing){
        initializing = false;
        initPosition();
    }
    
    // モータの制御更新
    motor1.update();
    motor2.update();
}

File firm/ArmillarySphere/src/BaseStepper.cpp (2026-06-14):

#include <stdlib.h>
#include <stdint.h>
#include "BaseStepper.h"

// 変数の初期化
void BaseStepper::init()
{
  pos_now = 0;
  pos_target = 0;
  infinit = false;
}

// 更新(じゅうぶん短い周期で呼ぶ)
void BaseStepper::update()
{
  if((pos_now != pos_target) || (infinit == true))
  {
    int now = getTime();
    int elapse = now - t0;
    if(elapse >= tn)
    {
      takeStep((dir * POL > 0) ? 1 : 0, n % 2);
      if((n % 2) == 0) pos_now += dir;
      n++;
      tn = (int)((int64_t)T * (int64_t)n / (int64_t)N);
    }
  }
}

// 停止
void BaseStepper::stop()
{
  pos_target = pos_now;
  infinit = false;
}

// 停止中か？
bool BaseStepper::isIdle()
{
  return ((pos_now == pos_target) && (infinit == false));
}

// ステップ数だけ回転
// step: ステップ数
// msec: 時間[msec]
void BaseStepper::setStepT(int step, int msec)
{
  if(step == 0) return;

  this->pos_target = this->pos_now + step;
  this->dir = (step>=0) ? 1 : -1;
  this->n = 1;
  this->N = abs(step) * 2;
  this->T = msec * 1000;
  this->t0 = getTime();
  this->tn = T / N;
  
  this->infinit = false;
}

// ステップ数だけ回転
// step: ステップ数
// sps: 速度[step/sec]
void BaseStepper::setStepV(int step, int sps)
{
  if(step == 0) return;
  if(sps == 0) return;

  this->pos_target = this->pos_now + step;
  this->dir = (step>=0) ? 1 : -1;
  this->n = 1;
  this->N = abs(step) * 2;
  this->T = (int)((int64_t)abs(step) * 1000000 / (int64_t)sps);
  this->t0 = getTime();
  this->tn = T / N;
  
  this->infinit = false;
}

// 目標位置まで回転
// pos: 目標位置
// msec: 時間[msec]
void BaseStepper::setPosT(int pos, int msec)
{
  if(pos == this->pos_now) return;

  this->pos_target = pos;
  int step = this->pos_target - this->pos_now;
  this->dir = (step>=0) ? 1 : -1;
  this->n = 1;
  this->N = abs(step) * 2;
  this->T = msec * 1000;
  this->t0 = getTime();
  this->tn = T / N;
  
  this->infinit = false;
}

// 目標位置まで回転
// pos: 目標位置
// sps: 速度[step/sec]
void BaseStepper::setPosV(int pos, int sps)
{
  if(pos == this->pos_now) return;
  if(sps == 0) return;

  this->pos_target = pos;
  int step = this->pos_target - this->pos_now;
  this->dir = (step>=0) ? 1 : -1;
  this->n = 1;
  this->N = abs(step) * 2;
  this->T = (int)((int64_t)abs(step) * 1000000 / (int64_t)sps);
  this->t0 = getTime();
  this->tn = T / N;
  
  this->infinit = false;
}

// 指定角度だけ回転
// deg: 角度[deg]
// sec: 時間[sec]
void BaseStepper::rotateT(double deg, double sec)
{
  int step = SPR * deg / 360;
  setStepT(step, (int)(sec*1000));
}

// 指定角度だけ回転
// deg: 角度[deg]
// dps: 速度[deg/sec]
void BaseStepper::rotateV(double deg, double dps)
{
  int step  = SPR * deg / 360;
  int V     = SPR * dps / 360;
  setStepV(step, V);
}

// 目標角度まで回転
// deg: 角度[deg]
// sec: 時間[sec]
void BaseStepper::moveT(double deg, double sec)
{
  int pos = SPR * deg / 360;
  setPosT(pos, (int)(sec*1000));
}

// 目標角度まで回転
// deg: 角度[deg]
// dps: 速度[deg/sec]
void BaseStepper::moveV(double deg, double dps)
{
  int pos = SPR * deg / 360;
  int V   = SPR * dps / 360;
  setPosV(pos, V);
}

// 無限回転 (ステップ数ベース)
// sps: 速度[step/sec] ※正負があることに注意
void BaseStepper::setV(int sps)
{
  int step = (sps >= 0) ? SPR : -SPR;
  sps = abs(sps);
  setStepV(step, sps);

  this->infinit = true;
}

// 無限回転 (角度ベース)
// dps: 速度[deg/sec] ※正負があることに注意
void BaseStepper::rotateV(double dps)
{
  int V   = SPR * dps / 360;
  setV(V);
}

// 位置の取得
// return: ステップ位置
int BaseStepper::getPos()
{
    return this->pos_now;
}

// 角度の取得
// return: 角度[deg]
int BaseStepper::getAngle()
{
    return (360 * this->pos_now / SPR);
}

// 位置のリセット
void BaseStepper::resetPos()
{
    pos_now = 0;
    pos_target = 0;
    infinit = false;
}

// 位置の換算 (±180°に相当する範囲の値に)
void BaseStepper::modPos()
{
    pos_now = pos_now % SPR;
    if (pos_now > (SPR/2)) pos_now -= SPR;
    pos_target = pos_now;
    infinit = false;
}

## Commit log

2023-05-30 fix app and firmware
    [BleCommand.cpp]
2026-06-08 fix firmware (Arduino IDE to PlatformIO)
    [ArmillarySphere.cpp, BaseStepper.cpp, BleCommand.cpp]
2026-06-08 add hardware.xlsx
    [hardware.xlsx]
2026-06-09 update hardware data
    [hardware.xlsx]
2026-06-11 add schematic
2026-06-14 bug fix (time zone)
    [ArmillarySphere.cpp, BleCommand.cpp]
2026-06-15 port to M5Stack
    [hardware.xlsx]
2026-06-18 add mechanical design
    [ArmillarySphere.f3d]
2026-06-23 add stl files
    [ControllerCace_bottom.stl, ControllerCace_top.stl, ControllerCase.f3d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]
2026-06-23 move files
    [ArmillarySphere.f3d, ControllerCace_bottom.stl, ControllerCace_top.stl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]
2026-07-03 modify mechanical design
    [ControllerCace_bottom.stl, ControllerCace_top.stl, ControllerCase.f3d]
2026-07-18 modify 3d model
    [ArmillarySphere.f3d]
2026-10-07 add 3D models
    [hall_adapter.stl, meridian_spacer.stl, meridian_spacer_2.stl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]
2026-10-07 modify mechanical design ( for assembly )
2026-10-08 add assembly manual
2026-10-08 modify assembly manual
2026-10-15 add enable control of steppers
